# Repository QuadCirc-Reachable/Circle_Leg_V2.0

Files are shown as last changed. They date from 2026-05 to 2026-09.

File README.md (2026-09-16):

# Circle_Leg_V2 — REACHABLE (QuadCirc) Full-Size Wheel-Leg Wheelchair Firmware

<p align="center">
  
  
  
  
  
</p>

<p align="center">
  <b>English</b> | <a href="README_zh.md">中文</a>
</p>

<p align="center">
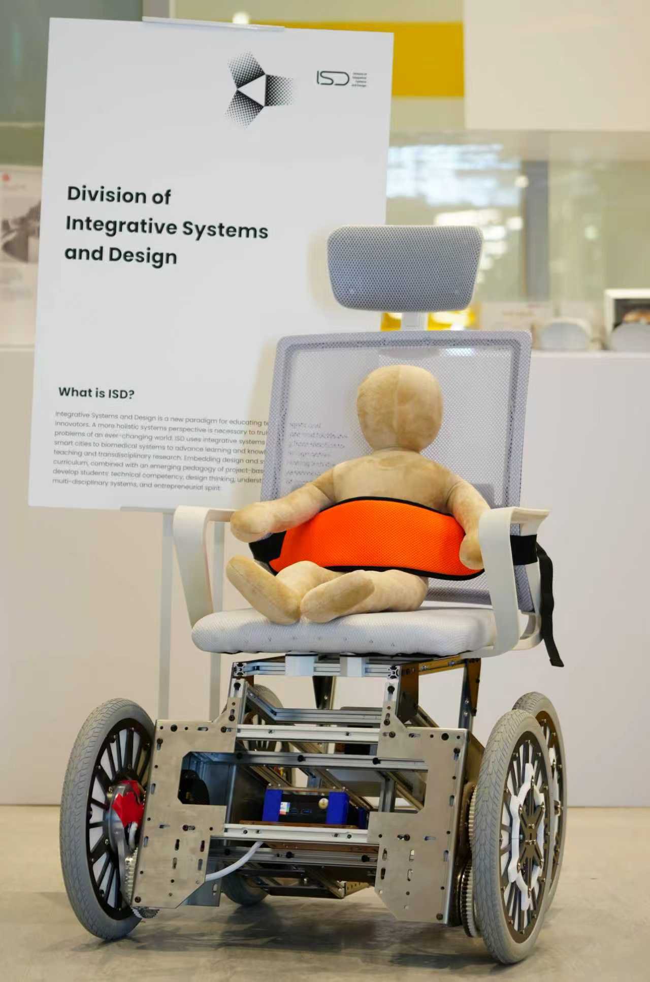
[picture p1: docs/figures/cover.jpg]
Full-size REACHABLE prototype on display at HKUST ISD
  
</p>
<p align="center"><sub>The full-size prototype on display at HKUST ISD</sub></p>

Embedded control firmware for the **full-size REACHABLE (QuadCirc) electric wheelchair**. It has four
**CircLeg** eccentric wheel-leg modules. Each one rolls as an ordinary wheel on flat ground and turns
into a stepping leg to lift the chassis over the 5–18 cm curbs, thresholds and single steps that
wheelchair users meet every day. HKUST Final Year Design Project **SL05a-25** (2025–2026).

---

## Overview

Each CircLeg puts the wheel hub at an eccentric offset *r* inside a wheel of radius *R*. Rotating
the hub raises or lowers that corner of the chassis, and the wheel stays in contact with the ground
the whole time. With only **two motors per corner** (one wheel motor, one leg motor), the firmware:

- **Drives** like a normal wheelchair: skid-steer inverse kinematics for the trapezoidal chassis,
  four D-pad speed tiers, acceleration limits and smoothing.
- **Rides comfortably (COMFORT mode):** variable-impedance active suspension that maps a virtual
  Cartesian spring-damper to per-leg MIT gains, IMU body leveling, an online mass estimate, and
  **warp** (diagonal-twist) compensation that keeps all four wheels grounded.
- **Climbs steps (CLIMBING mode):** a per-leg state machine that detects step contact from the
  motor **torque residual** plus the wheel-speed drop, then follows a purely geometric climbing
  trajectory. The front pair climbs first and the back pair follows.
- **Stays safe:** host link-loss detection (500 ms), smooth mode transitions, singularity clamping,
  and live-tunable debug structs for SEGGER Ozone.

Related repositories:

| Repository | Content |
|---|---|
| **Circle_Leg_V2** (this repo) | Firmware for the full-size prototype (final deliverable), PCB and CAD |
| [Circle_Leg_V1.0](https://github.com/QuadCirc-Reachable/Circle_Leg_V1.0) | Firmware for the half-size proof-of-concept prototype |
| [Circle_Leg_Host_V2.0](https://github.com/QuadCirc-Reachable/Circle_Leg_Host_V2.0) | Host software: gamepad link + optional RealSense curb vision (Python package) |
| [Circle_Leg_Host_V1.0](https://github.com/QuadCirc-Reachable/Circle_Leg_Host_V1.0) | Previous single-script gamepad → UART bridge |

---

## Demo

<p align="center">
  <a href="https://youtu.be/onJCvx1d8Sw">
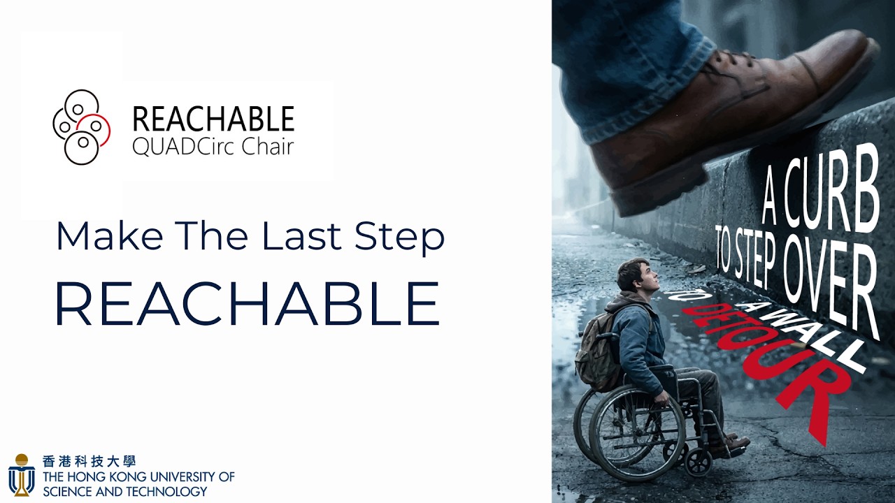
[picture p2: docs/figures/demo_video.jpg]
REACHABLE pitch video on YouTube
    
  </a>
</p>

<p align="center">
  ▶ <a href="https://youtu.be/onJCvx1d8Sw">Watch the REACHABLE pitch video on YouTube</a>
</p>

---

## Key Results

Full-size prototype, as reported in the team's final project report (June 2026):

| Objective | Target | Demonstrated |
|---|---|---|
| Basic locomotion | ≥ 1.2 m/s, differential steering | **1.49 m/s** operating (up to ≈ 2.2 m/s), emergency stop on link loss |
| CircLeg actuation | ±180° within 3 s | **≈ 0.8 s**, critically damped |
| Step climbing | 5–18 cm, seat pitch within ±15° | **5–18 cm**, seat pitch within **±5°** |
| Attitude & suspension | Level within ±10° on slopes | Chassis level within **±2–3°**; warp compensation operational |

> Measured with on-board telemetry (motor encoders, IMU, CAN-reported current) and debugger
> inspection, not with external instruments.

---

## System Architecture

```
┌──────────────────────────┐  UART 2 Mbit/s (CH343)   ┌──────────────────────────────────────────────┐
│ Host (Jetson Orin Nano)  │ ── PC_Msg @ 30 Hz ─────► │ STM32G473 · FreeRTOS                         │
│ Circle_Leg_Host_V2       │ ◄── Reachable_Msg ────── │                                              │
│ Xbox gamepad → frames    │                          │  PC_Comm (link watchdog 500 ms)              │
└──────────────────────────┘                          │     │                                        │
                                                      │     ▼                                        │
┌──────────────────────────┐        SPI               │  Chassis_Task  (500 Hz, 2 ms)                │
│ IMU  ICM-42688-P         │ ───────────────────────► │  ┌────────────────────────────────────────┐  │
└──────────────────────────┘                          │  │ Chassis state machine                  │  │
                                                      │  │ IDLE · ENERGY_SAVING · COMFORT · CLIMB │  │
                                                      │  ├────────────────────────────────────────┤  │
                                                      │  │ Impedance · GroundContact (warp) ·     │  │
                                                      │  │ Climbing FSM · Body PID · Inverse kin. │  │
                                                      │  └───────────────────┬────────────────────┘  │
                                                      │        Wheel_Leg ×4 (FL · FR · BL · BR)       │
                                                      └──────────┬─────────────────────┬─────────────┘
                                                        CAN 1 Mbit/s            CAN 1 Mbit/s
                                                                 ▼                     ▼
                                                  4× HT8115 wheel motors   4× DM J10010L-2EC leg motors
                                                  (MIT velocity mode)      (MIT impedance mode)
```

<p align="center">
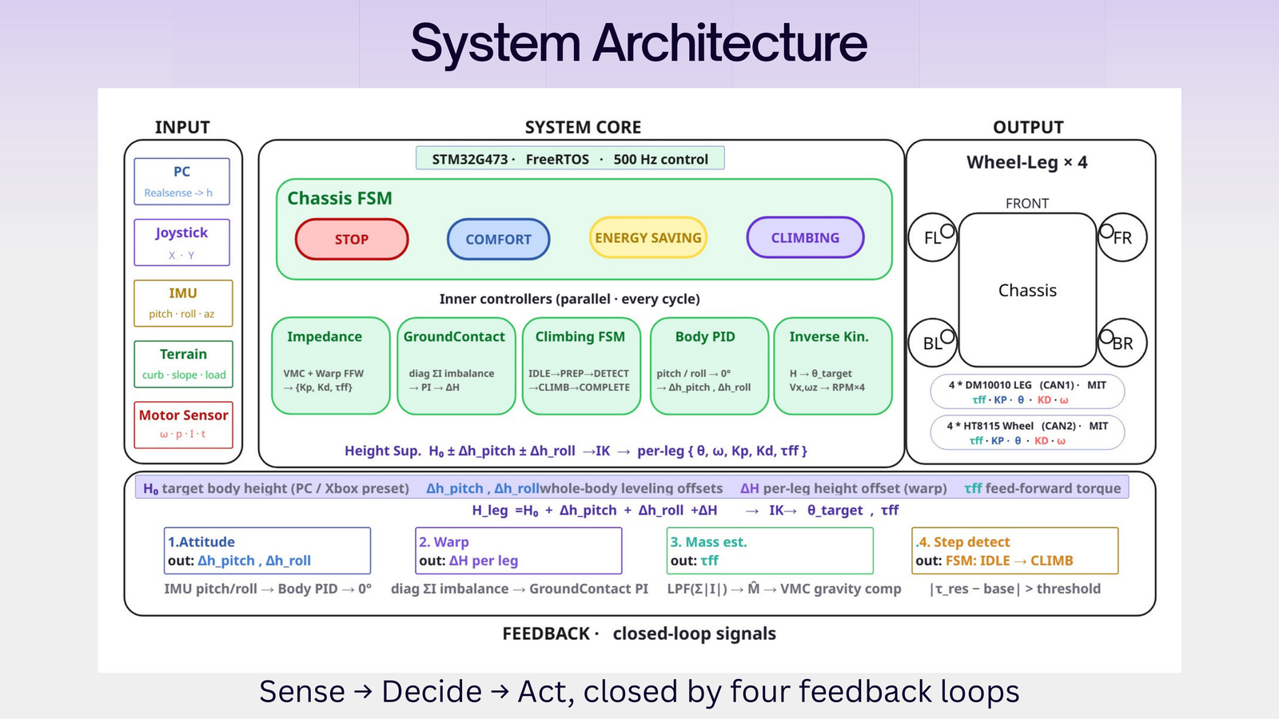
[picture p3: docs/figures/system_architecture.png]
System architecture
  
</p>

Every 2 ms the chassis task reads the latest gamepad command and the IMU attitude. It runs the
active mode's controllers, turns per-leg **height** targets into leg angles and MIT commands
`{θ, ω, Kp, Kd, τ_ff}`, sends one CAN frame per motor, and queues the telemetry for the host.

---

## Control Design

### Eccentric wheel-leg kinematics

<p align="center">
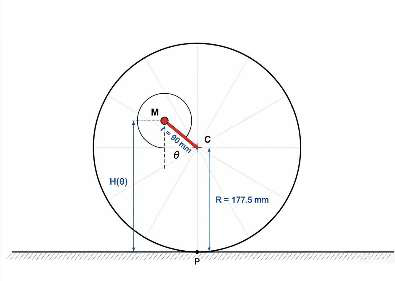
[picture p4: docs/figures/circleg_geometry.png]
CircLeg geometry
  
</p>

With the hub offset *r* = 90 mm inside a wheel of radius *R* = 177.5 mm, the V2 firmware measures
the leg angle from the **lowest** pose (θ = 0°) to the **highest** pose (θ = 180°):

$$H(\theta) = R - r\cos\theta, \qquad \theta = \arccos\frac{R - H}{r}, \qquad \frac{\partial H}{\partial \theta} = r\sin\theta$$

The Jacobian vanishes at 0° and 180°, so every controller clamps the working range away from these
singularities.

### Chassis modes

| Mode | Wheels | Legs | Notes |
|---|---|---|---|
| **IDLE** | Stopped | Low-stiffness hold | Safe state; also entered on host link loss |
| **ENERGY_SAVING** | Joystick | Near 0° (lowest stance), stiff hold | Minimum power; ramps smoothly when leaving COMFORT |
| **COMFORT** | Joystick | Variable-impedance suspension + leveling + warp | Height presets on A/X/LB/RB/Y/B |
| **CLIMBING** | Joystick + auto advance | Per-leg climbing FSM | Front pair first, back pair follows |

`ML` / `MR` step backwards / forwards through IDLE → ENERGY_SAVING → COMFORT → CLIMBING. The
CALIBRATION, FREE_CONTROL and DEBUG states are compiled in but not in the live cycle. The DM leg
motors store their zero at the lowest pose in flash, so no calibration is needed at power-up.

### COMFORT — variable-impedance suspension

A virtual Cartesian spring-damper $(k_v, c_v)$ at each wheel contact point is mapped into joint
space through the eccentric Jacobian:

$$K_{p,i} = \left(\frac{\partial H}{\partial \theta_i}\right)^2 k_{v,i}, \qquad K_{d,i} = \left(\frac{\partial H}{\partial \theta_i}\right)^2 c_v, \qquad \tau_{ff,i} = \left(\frac{\hat M}{4} + m_\text{leg}\right) g \,\frac{\partial H}{\partial \theta_i} + \tau_{\text{warp},i}$$

- **Mass estimate** $\hat M$: low-pass-filtered sum of leg currents. It is frozen while the height
  target is slewing, so the unloading transient doesn't collapse the feed-forward.
- **Body leveling**: roll / pitch PID loops output per-leg height offsets. Gyro-rate damping and a
  load-adaptive gain scale keep the same tuning stable with or without a rider.
- **Warp**: see below. Overloaded diagonals get softer $k_v$ and underloaded ones are pushed down.

### Warp compensation

<p align="center">
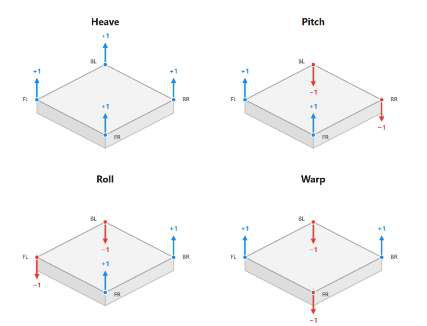
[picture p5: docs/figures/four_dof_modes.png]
Heave, pitch, roll and warp modes
  
</p>

A rigid four-contact chassis has four height modes: heave, pitch, roll and **warp**. Pitch and roll
PID loops can't see warp, so on uneven floors one wheel can hang in the air. The firmware measures
warp directly from the diagonal current imbalance, with no extra sensor:

$$e_\text{warp} = \tfrac12\left(I_{FL} + I_{BR}\right) - \tfrac12\left(I_{FR} + I_{BL}\right)$$

It closes a dedicated loop on it: Kp / feed-forward modulation in COMFORT, and a PI loop on the
per-leg height offset in CLIMBING.

### CLIMBING — step-climbing pipeline

```
HOMING_IN ──► WAIT_START ──(X)──► PREP ──► DETECT ──► CLIMBING ──► COMPLETE ──► HOMING_OUT
 legs → 0°     hold at 0°          lift to    torque-residual  geometric    front pair done →
                                   165°, lean + wheel-drop     trajectory   nose-down lean,
                                   nose-up    score ≥ 1        (kinematic)  back pair repeats
```

- **Detection**: the torque residual $\tau_\text{res} = \tau_\text{fb} - \tau_\text{gravity}$ is tracked
  against an adaptive baseline and combined with a wheel-speed-drop score. Front and back legs have
  separate thresholds, and detection is inhibited while turning.
- **Trajectory**: the leg angle follows the geometry of a wheel rolling over the step edge, with
  step height *h* as a parameter. Auto chassis advance pushes the chassis through while the front
  wheels sit on the step.
- **Weight shift**: nose-up lean while the fronts climb. Afterwards a front-leg drop moves the CoM
  forward to unload the back wheels. Every offset is eased in and out with smoothstep ramps.
- Once both front legs are COMPLETE, pressing **X** again forces the back pair to climb, bypassing
  the detection gates, in case automatic detection doesn't fire.

The full design log, including every tuning decision behind the `dbg_ctrl` parameters, is in
[docs/UNIFIED_CONTROL_REFACTOR.md](docs/UNIFIED_CONTROL_REFACTOR.md).

### Locomotion

The trapezoidal chassis uses per-axle skid-steer gains so it tracks straight lines without drifting:

$$V_{FL/BL} = V_x - \omega_z k_{F/B}, \qquad V_{FR/BR} = V_x + \omega_z k_{F/B}, \qquad k_{F} = \frac{W_F}{W_\text{avg}},\; k_{B} = \frac{W_B}{W_\text{avg}}$$

A wheel-leg decoupling feed-forward cancels the wheel motion that hub rotation would otherwise cause,
so the chair doesn't lurch when the ride height changes.

---

## Repository Structure

```
Circle_Leg_V2/
├── Applications/                   # Application layer (this project)
│   ├── Chassis.hpp/.cpp            # Mode state machine, leveling, IK, climbing orchestration
│   ├── Chassis_Task.hpp/.cpp       # FreeRTOS 500 Hz control task
│   ├── Wheel_Leg.hpp/.cpp          # One CircLeg corner: height↔angle, MIT leg pipeline, wheel loop
│   ├── Impedance_Controller.*      # Variable-impedance suspension, mass estimate, warp modulation
│   ├── Ground_Contact.*            # Warp PI compensator
│   ├── Climbing_Dynamics.*         # Per-leg climbing FSM, step detection, trajectory
│   ├── Controller.*                # Joystick → (Vx, Wz), D-pad speed tiers, slew + LPF
│   ├── PC_Comm.*                   # Host UART link (RosComm framing), link watchdog
│   ├── Robot_Config.*              # Motor objects, CAN IDs, per-leg parameters
│   ├── Robot_Params.hpp            # Geometry, masses, IMU mounting, gains, limits
│   ├── Comm_Msg.hpp                # PC_Msg / Reachable_Msg layouts, button bitmasks
│   ├── Cust_Types.hpp, Helper.hpp  # Shared types and helpers
│   └── DM_Motor_Test.*             # Stand-alone DM J10010L bring-up test (USE_DM_MOTOR_TEST)
├── Core/                           # CubeMX HAL init + UserTask.cpp (task creation)
├── Drivers/, Middlewares/          # STM32G4 HAL, CMSIS, CMSIS-DSP (vendor)
├── RM2025-Core/                    # Submodule → private RM2025-Core (motors, CAN, IMU, RTOS)
├── hardware/
│   ├── power-distribution-board/   # KiCad 9 PCB: dual-battery 24 V power distribution
│   └── interface-cad/              # SolidWorks interface assembly and parts
├── docs/
│   ├── TECHNICAL_REPORT.md         # Control-system technical report (derivations)
│   ├── UNIFIED_CONTROL_REFACTOR.md # Climbing / leg-control design log
│   ├── CODE_STRUCTURE.txt          # Class map and control-flow notes
│   └── figures/
├── Makefile, Core.mk               # GNU Make build (arm-none-eabi-gcc)
├── RM2024-Template-G473.ioc        # STM32CubeMX project
├── stm32g473vetx_flash.ld          # Linker script
└── startup_stm32g473xx.s
```

---

## Getting Started

### Prerequisites

- `arm-none-eabi-gcc` (tested with GCC 12.2 from MSYS2) and GNU Make
- A SWD probe: SEGGER J-Link (Ozone / J-Flash) or ST-Link (STM32CubeProgrammer)
- Read access to the private
  [QuadCirc-Reachable/RM2025-Core](https://github.com/QuadCirc-Reachable/RM2025-Core) repository

> **RM2025-Core** is an internal library of the HKUST ENTERPRIZE RoboMaster team. It is linked as a
> git submodule pointing to a private repository and is **not** part of this repository's contents.

### Clone & build

```bash
git clone --recurse-submodules https://github.com/QuadCirc-Reachable/Circle_Leg_V2.0.git
cd Circle_Leg_V2.0
# already cloned without submodules?  git submodule update --init

make -j8
# → build/RM2024-Template-G473.elf / .hex / .bin
```

Every commit pins the exact RM2025-Core snapshot it was built with, so checking out any old commit
and running `git submodule update` rebuilds it byte-for-byte.

### Flash & debug

Flash `build/RM2024-Template-G473.elf` (or `.hex`) over SWD with Ozone, J-Flash or
STM32CubeProgrammer. For live tuning, open the ELF in SEGGER Ozone and watch or edit these globals:

| Global | Purpose |
|---|---|
| `dbg_ctrl` | Live-tunable climbing parameters (thresholds, pitch bias, ramps, speed ratios) |
| `DbgSummary` / `dbg_climb_plot` | Most useful signals for plotting at 500 Hz |
| `dbg_wheel_test_enable` / `dbg_wheel_test_rpm` | Wheel test bypass (`CHASSIS_DEBUG_SNAPSHOT`) |

### Configuration

| File | What to change |
|---|---|
| `Applications/Robot_Params.hpp` | Geometry, masses, IMU mounting / level trim, speed tiers, leveling gains, limits |
| `Applications/Robot_Config.cpp` | Motor IDs, CAN bus, direction flags |
| `Core/Inc/AppConfig.h` | RM2025-Core module switches (IMU, DM / HT motors, RosComm, `USE_DM_MOTOR_TEST`) |

---

## Operator Controls

Xbox gamepad on the host (see [Circle_Leg_Host_V2.0](https://github.com/QuadCirc-Reachable/Circle_Leg_Host_V2.0)):

| Input | Function |
|---|---|
| Left stick | Forward / backward speed |
| Right stick | Turn rate |
| `ML` / `MR` (View / Menu) | Previous / next chassis mode |
| D-pad ↓ ← → ↑ | Speed tier LOW 20 / MID_LOW 40 (default) / MID_HIGH 80 / HIGH 120 wheel RPM |
| `A` `X`/`LB` `RB` `Y` `B` | COMFORT ride-height presets: leg angle 45° / 90° / 135° / 145° / 165° |
| `X` in CLIMBING | Start the climb (WAIT_START → PREP); once the front pair is COMPLETE, press again to force the back pair |

---

## Communication Protocol

USART2 at **2 Mbit/s**, RosComm framing with CRC16:

```
| SOF 0xAA | len | ID 0xFF | CRC16(header) | payload (14 B) | CRC16(frame) |   → 21 bytes
```

`PC_Msg` (host → MCU, little-endian, packed):

| Field | Type | Range / meaning |
|---|---|---|
| `left_joystick.angle_x10_msg` | int16 | 0–3600 (deg × 10), −1 = released |
| `left_joystick.r_x1000_msg` | uint16 | 0–1000 (deflection) |
| `right_joystick.angle_x10_msg` | int16 | 0–3600, −1 = released |
| `right_joystick.r_x1000_msg` | uint16 | 0–1000 |
| `Left_trigger_x1000_msg` / `Right_trigger_x1000_msg` | uint16 | 0–1000 |
| `button_status` | uint8 | bit 0–7: LB, RB, X, A, B, Y, ML, MR |
| `dpad_status` | uint8 | bit 0–3: Up, Down, Left, Right |

`Reachable_Msg` (MCU → host, 40 bytes) reports each corner's leg position (deg × 10) and wheel RPM.
The field names still say GM6020 / M3508, left over from the half-size hardware.

Host V2.0 can also send RealSense curb-detection results (`0xFC`) and accept a vision-control
heartbeat (`0xFD`). This firmware consumes only the `0xFF` gamepad link. The MCU-side changes
needed to close the vision-in-the-loop climb are in Host V2.0's
[MCU integration guide](https://github.com/QuadCirc-Reachable/Circle_Leg_Host_V2.0/blob/main/docs/MCU_Integration_Guide.md).

---

## Hardware

<div align="center">
<table>
  <tr>
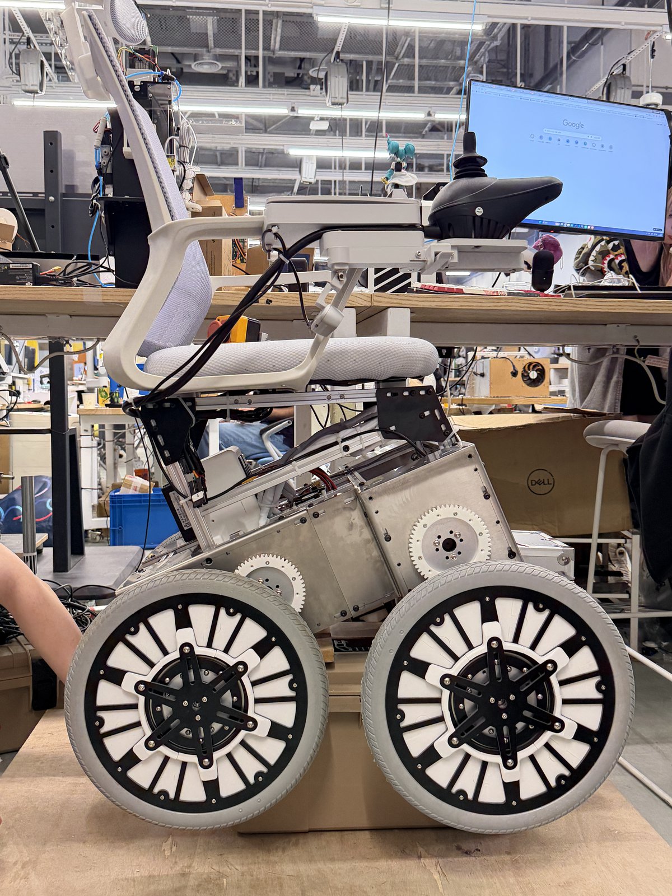
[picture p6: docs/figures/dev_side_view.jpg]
Side view of the full-size prototype during development
    <td align="center"><br><sub>Side view during development</sub></td>
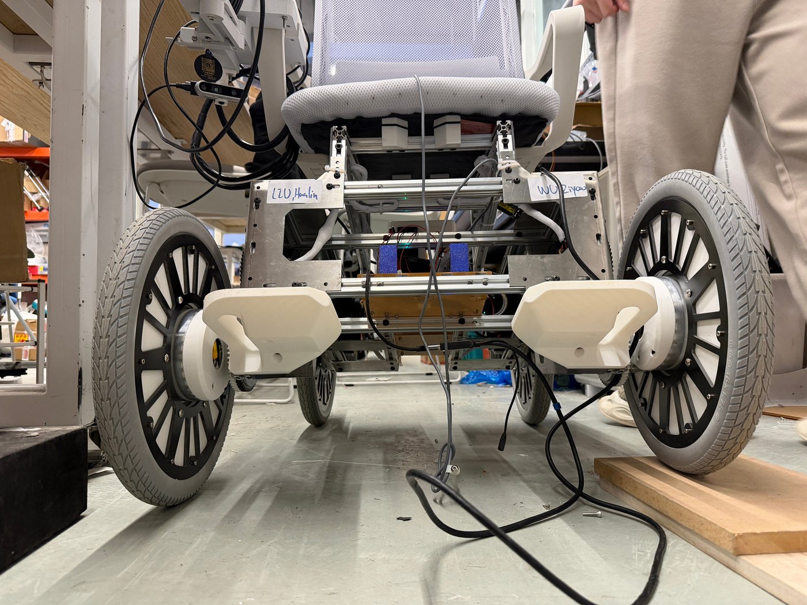
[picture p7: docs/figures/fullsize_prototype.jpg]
CircLeg modules, front view
    <td align="center"><br><sub>CircLeg modules, front view</sub></td>
  </tr>
</table>
</div>

| Item | Specification |
|---|---|
| MCU | STM32G473VET6, Cortex-M4F @ 170 MHz (ENTERPRIZE G4 control board) |
| RTOS | FreeRTOS, 1 kHz tick; chassis task 500 Hz |
| Wheel motors | 4× HT8115, MIT velocity mode |
| Leg motors | 4× DM J10010L-2EC, MIT impedance mode |
| Buses | 2× classic CAN @ 1 Mbit/s (FDCAN peripheral); USART2 @ 2 Mbit/s to host |
| IMU | ICM-42688-P (SPI) |
| Geometry | *R* = 177.5 mm, *r* = 90 mm; track 620 / 480 mm (front / back), wheelbase 385 mm |
| Mass | ≈ 39 kg vehicle |
| Power | 2× DJI TB48 (22.8 V); 24→19 V and 24→5 V converters |
| Host | Jetson Orin Nano + Intel RealSense D435 (curb perception) |

### Power distribution board

`hardware/power-distribution-board/` is a KiCad 9 project. Two battery inputs are OR-ed through
LM74700 ideal-diode controllers with BSC070N10NS5 MOSFETs, with TVS protection and a fuse. The
24 V rail is split to eight motor ports (four leg, four chassis), the mini PC, the control board and
a fan, using XT30 connectors. Custom footprints are in `Library.pretty/`. Jason Chan helped
develop this board.

### Interface CAD

`hardware/interface-cad/` holds the SolidWorks assembly `Assem3.SLDASM` and its parts.

---

## Documentation

| Document | Content |
|---|---|
| [docs/TECHNICAL_REPORT.md](docs/TECHNICAL_REPORT.md) | Control-system report: kinematics, leveling, impedance, warp, climbing, RTOS |
| [docs/UNIFIED_CONTROL_REFACTOR.md](docs/UNIFIED_CONTROL_REFACTOR.md) | Climbing pipeline and leg-control design log, with tuning history |
| [docs/CODE_STRUCTURE.txt](docs/CODE_STRUCTURE.txt) | Class hierarchy, per-mode control flow, key formulas |

---

## Team

<p align="center">
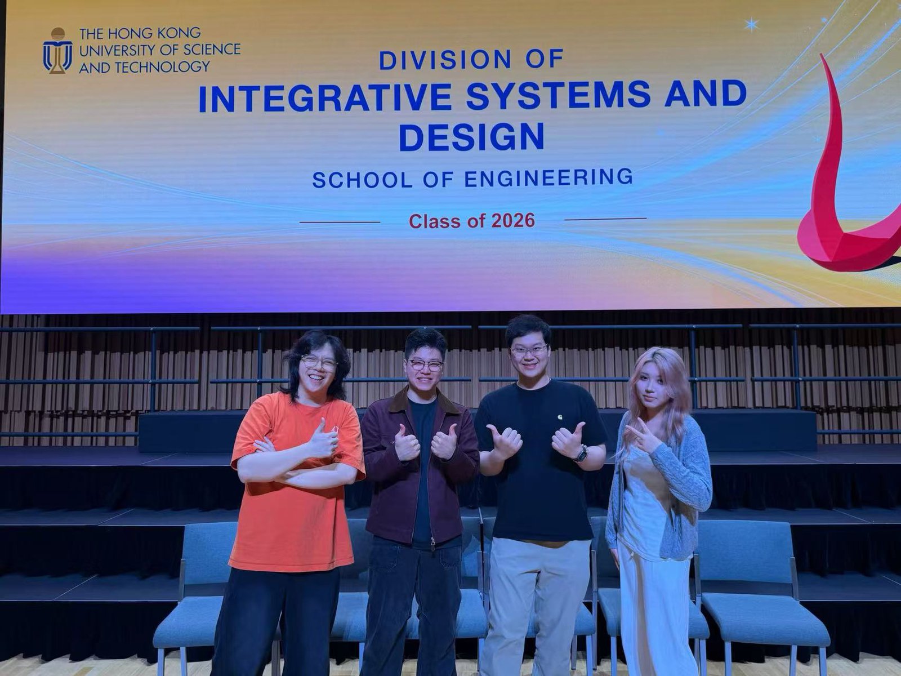
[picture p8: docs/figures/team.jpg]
The REACHABLE team at the HKUST ISD Class of 2026 event
  
</p>

**REACHABLE (QuadCirc)**, HKUST Final Year Design Project SL05a-25:

- **LIU Hualin** — embedded control lead: motor and MCU selection, dual-CAN hardware, and all of the firmware and control algorithms in this repository
- **FANG Ruoyun** — perception (RealSense curb detection) and HMI
- **WU Ziyao** — mechanical architecture, host–MCU communication
- **XU Jusen** — mechanical lead (CircLeg bracket, chassis, DFM/DFA)

Supervisors: Prof. Chi-Ying TSUI and Prof. Winnie Suk Wai LEUNG; co-supervisor Prof. SHI Ling.

---

## License

The application code in this repository is released under the [MIT License](LICENSE).
Third-party components keep their own licenses: STM32 HAL / CMSIS in `Drivers/` and `Middlewares/`,
and template files (`Core.mk`, `Core/Src/UserTask.cpp`) from the ENTERPRIZE RoboMaster team.
The `RM2025-Core` submodule is private and not covered by this license.

## Acknowledgments

- HKUST ENTERPRIZE RoboMaster team for RM2025-Core and the G4 project template
- Jason GAN (RM2024) for the original HT8115 motor driver
- Jason Chan for helping develop the power distribution board
- STMicroelectronics (HAL, CMSIS) and the FreeRTOS project
- Our friends and classmates at HKUST ISD

<p align="center">
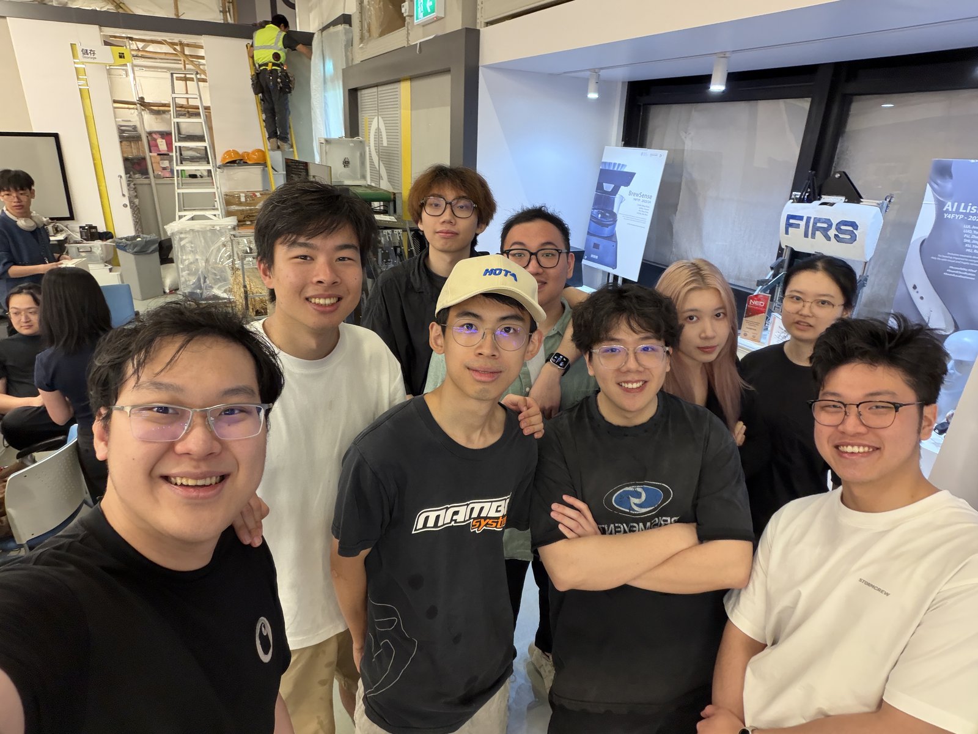
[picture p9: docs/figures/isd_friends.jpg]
With friends from HKUST ISD
  
</p>
<p align="center"><sub>With our friends from HKUST ISD</sub></p>

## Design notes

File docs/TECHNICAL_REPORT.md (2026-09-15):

# Circle Leg V1 — Final Year Project Technical Report

> **Scope note (Circle_Leg_V2):** this report was written for the half-size prototype (Circle_Leg_V1: M3508 wheels, HT8115 legs) and uses V1's angle convention $H(	heta) = R + r\cos	heta$. The control architecture carries over to V2 unchanged; see the [README](../README.md) for the full-size hardware, parameters and V2's convention $H(	heta) = R - r\cos	heta$ (legs zeroed at the lowest pose).

## Table of Contents

1. [Project Overview](#1-project-overview)
2. [System Architecture](#2-system-architecture)
3. [Hardware Configuration](#3-hardware-configuration)
4. [Eccentric Wheel-Leg Kinematics](#4-eccentric-wheel-leg-kinematics)
5. [Chassis State Machine](#5-chassis-state-machine)
6. [Body Leveling — Pitch/Roll PID](#6-body-leveling--pitchroll-pid)
7. [Inverse Kinematics — Skid-Steer Model](#7-inverse-kinematics--skid-steer-model)
8. [Wheel–Leg Decoupling Compensation](#8-wheel-leg-decoupling-compensation)
9. [Virtual Model Control (VMC)](#9-virtual-model-control-vmc)
10. [Impedance Controller — Active Suspension](#10-impedance-controller--active-suspension)
11. [Ground Contact — Warp Compensation](#11-ground-contact--warp-compensation)
12. [Climbing Dynamics — Step Climbing](#12-climbing-dynamics--step-climbing)
13. [Motor Control Pipeline](#13-motor-control-pipeline)
14. [Communication Protocol](#14-communication-protocol)
15. [RTOS Task Structure](#15-rtos-task-structure)
16. [Summary of Key Formulas](#16-summary-of-key-formulas)
17. [File Reference](#17-file-reference)

---

## 1. Project Overview

This project implements a **4-wheeled eccentric-leg robot** (Circle Leg) on an **STM32G473** microcontroller, running **FreeRTOS** at a **500 Hz** control loop. The robot features:

- **Four independent wheel-leg units**, each consisting of a **wheel motor** (DJI M3508) and a **leg motor** (HT8115, MIT control mode).
- **Variable-impedance active suspension** (Comfort Mode) for terrain adaptation.
- **Kinematic step-climbing** (Climbing Mode) using torque-residual step detection and geometric trajectory planning.
- **Ground contact warp compensation** to maintain 4-wheel ground contact on uneven surfaces.
- **PC remote control** via UART with joystick and button inputs.

---

## 2. System Architecture

```
┌──────────────────────────────────────────────────────┐
│                    PC Controller                     │
│           (Joystick + Buttons via UART)              │
└──────────────┬───────────────────────────────────────┘
               │  PC_Msg (13 bytes)
               ▼
┌──────────────────────────────────────────────────────┐
│              Chassis_Task (500 Hz)                   │
│  ┌────────────────────────────────────────────────┐  │
│  │              Chassis (State Machine)            │  │
│  │  ┌──────────┐ ┌──────────┐ ┌──────────────┐   │  │
│  │  │ Pitch/   │ │Impedance │ │  Climbing    │   │  │
│  │  │ Roll PID │ │Controller│ │  Dynamics    │   │  │
│  │  └──────────┘ └──────────┘ └──────────────┘   │  │
│  │  ┌──────────┐ ┌──────────┐                    │  │
│  │  │  Ground  │ │  Inverse │                    │  │
│  │  │  Contact │ │Kinematics│                    │  │
│  │  └──────────┘ └──────────┘                    │  │
│  └────────────────────────────────────────────────┘  │
│          │            │           │          │        │
│      ┌───┴───┐   ┌───┴───┐  ┌───┴───┐  ┌───┴───┐   │
│      │FL Leg │   │FR Leg │  │BL Leg │  │BR Leg │   │
│      │M3508+ │   │M3508+ │  │M3508+ │  │M3508+ │   │
│      │HT8115 │   │HT8115 │  │HT8115 │  │HT8115 │   │
│      └───────┘   └───────┘  └───────┘  └───────┘   │
└──────────────────────────────────────────────────────┘
```

---

## 3. Hardware Configuration

### 3.1 Mechanical Parameters

| Parameter | Symbol | Value | Unit |
|---|---|---|---|
| Wheel Radius | $R$ | 160 | mm |
| Eccentric Offset (Leg Length) | $r$ | 65 | mm |
| Wheelbase | $L$ | 270 | mm |
| Front Track Width | $W_F$ | 531 | mm |
| Back Track Width | $W_B$ | 395 | mm |
| Robot Mass | $M$ | 10.0 | kg |
| Leg Mass | $m_{leg}$ | 0.5 | kg |

### 3.2 Motor Configuration

| Motor | Type | Quantity | Bus | Role |
|---|---|---|-----|---|
| M3508 | Brushless DC (DJI) | 4 | CAN 2 | Wheel drive, PID velocity control |
| HT8115 | Torque motor | 4 | CAN 3 | Leg actuation, MIT impedance control |

### 3.3 IMU

- On-board IMU providing Euler angles (Yaw, Pitch, Roll), calibrated gyro, and earth-frame linear acceleration (gravity removed).
- IMU mounting roll offset: **182.91°** (compensated in software).
- Low-pass filter on angles: $\alpha = 0.02$ (~4 Hz cutoff at 500 Hz).

---

## 4. Eccentric Wheel-Leg Kinematics

Each wheel-leg unit uses an **eccentric linkage**: a motor rotates the leg by angle $\theta$, changing the chassis height.

### 4.1 Height–Angle Relationship

$$H(\theta) = R + r \cdot \cos(\theta)$$

Where:
- $H$ = ground-to-motor-center height (m)
- $R$ = wheel radius (m)
- $r$ = eccentric offset / leg length (m)
- $\theta$ = leg angle (0° = fully extended/highest, 180° = fully retracted/lowest)

### 4.2 Inverse: Height to Angle

Given a target height $H_{target}$:

$$\cos(\theta) = \frac{H_{target} - R}{r}$$

$$\theta = \arccos\left(\frac{H_{target} - R}{r}\right)$$

**Safety:** clamped to $[10°, 170°]$ to avoid singularities at 0° and 180°.

### 4.3 Velocity Feedforward (Height Rate to Angular Velocity)

From $\dot{H} = -r \sin(\theta) \cdot \dot{\theta}$:

$$\dot{\theta} = \frac{-\dot{H}}{r \cdot (\sin(\theta) + \epsilon)}$$

Where $\epsilon = 0.1$ is a damping term to avoid division-by-zero near singularities.

### 4.4 Bending Direction

Each leg has a `bending_direction` parameter ($+1$ or $-1$) that selects between the positive and negative angle solution, allowing the robot to switch between "outward" and "inward" leg configurations.

---

## 5. Chassis State Machine

The system operates through the following states, controlled by gamepad buttons:

| State | ID | Description |
|---|----|---|
| **CALIBRATION** | 0 | Re-enters HT motor mode, sets zero position, then transitions to IDLE |
| **IDLE** | 1 | All motors stopped, zero output |
| **ENERGY_SAVING** | 2 | Legs at 0° (folded), stiff position hold ($K_p=20$, $K_d=1.5$), basic wheel driving |
| **COMFORT** | 3 | **Variable-impedance active suspension** with IMU-based body leveling and warp compensation |
| **CLIMBING** | 4 | **Per-leg kinematic step climbing** with torque-residual detection, front-first then rear-legs |
| **FREE_CONTROL** | 5 | Direct trigger-to-angle mapping for manual leg positioning |
| **DEBUG** | 6 | Height control via buttons, no PID leveling (for testing) |

### Mode Transition

- **ML + MR** simultaneously → CALIBRATION
- **ML** (rising edge) → Previous state
- **MR** (rising edge) → Next state

### Smooth Kp Ramp on COMFORT Exit

When leaving COMFORT mode, the impedance Kp/Kd values are captured and linearly ramped to the target mode's values over **200 frames (0.4 s)** to prevent sudden torque changes:

$$K_p(t) = K_{p,\text{exit}} + \alpha(t) \cdot (K_{p,\text{target}} - K_{p,\text{exit}})$$

where $\alpha(t) = t / T_{ramp}$ increases from 0 to 1.

---

## 6. Body Leveling — Pitch/Roll PID

Two independent PID controllers maintain chassis level using IMU feedback:

| PID | $K_p$ | $K_i$ | $K_d$ | Integral Limit | Output Limit |
|-----|---|---|---|---|---|
| Roll | 0.015 | 0.0002 | 0.00012 | 1000 | 0.08 m |
| Pitch | 0.015 | 0.00015 | 0.00012 | 1000 | 0.08 m |

**PID output** is a height offset in meters. Distribution to four legs:

| Leg | Pitch Sign | Roll Sign |
|-----|---|---|
| FL (Front-Left)  | $+1$ | $-1$ |
| FR (Front-Right) | $+1$ | $+1$ |
| BL (Back-Left) | $-1$ | $-1$ |
| BR (Back-Right)  | $-1$ | $+1$ |

Per-leg target height:

$$H_i = H_{target} + s_{pitch,i} \cdot \Delta H_{pitch} + s_{roll,i} \cdot \Delta H_{roll} + \Delta H_{mode,i}$$

Where:
- $\Delta H_{pitch} = \text{PID}_{pitch}(0, \theta_{pitch})$
- $\Delta H_{roll} = \text{PID}_{roll}(0, \theta_{roll})$
- $\Delta H_{mode,i}$ = mode-specific compensation (warp, climbing, etc.)

---

## 7. Inverse Kinematics — Skid-Steer Model

The robot uses **asymmetric skid-steer** kinematics ($W_F \neq W_B$):

$$V_{FL} = V_x - \omega_z \cdot k_F, \qquad V_{FR} = V_x + \omega_z \cdot k_F$$

$$V_{BL} = V_x - \omega_z \cdot k_B, \qquad V_{BR} = V_x + \omega_z \cdot k_B$$

Where the differential gain per axle:

$$k_F = \frac{W_F}{W_{avg}}, \qquad k_B = \frac{W_B}{W_{avg}}, \qquad W_{avg} = \frac{W_F + W_B}{2}$$

**Normalization:** If any wheel RPM exceeds `MAX_WHEEL_RPM` (80 RPM), all four are proportionally scaled down.

### Joystick Mapping

- **Left stick** → Forward/backward velocity $V_x$ (max ±40 RPM)
- **Right stick** → Rotational velocity $\omega_z$ (max ±40 RPM)
- Deadzone: 200/1000 on radius magnitude

---

## 8. Wheel–Leg Decoupling Compensation

When the leg motor rotates, it mechanically couples into the wheel, causing unintended wheel spin. This is compensated by:

$$n_{wheel,comp} = n_{leg} \cdot \left(1 + \frac{r}{R} \cdot \cos(\theta_{leg})\right) \cdot k_{coupling}$$

Where:
- $n_{leg}$ = leg motor RPM
- $r / R$ = eccentric offset / wheel radius ratio
- $\theta_{leg}$ = current leg angle
- $k_{coupling}$ = coupling sign ($\pm 1$ depending on mounting geometry)

This compensation RPM is added to the wheel motor target before PID execution.

---

## 9. Virtual Model Control (VMC)

Converts a desired vertical force $F_z$ to motor torque via the mechanism Jacobian:

$$\tau = F_z \cdot r \cdot \cos(\theta)$$

Where $\tau$ is motor torque (Nm), $r$ is eccentric offset (m), and $\theta$ is leg angle (rad).

### Gravity Compensation

Each leg compensates for gravitational torque:

$$\tau_{gravity} = -(m_{leg} \cdot g \cdot r \cdot \cos(\theta))$$

This is continuously applied as **feed-forward torque** in the MIT control command.

---

## 10. Impedance Controller — Active Suspension

The core of COMFORT mode. Maps desired **Cartesian impedance** (spring-damper at the wheel contact point) to **joint-space MIT motor parameters**.

### 10.1 Theoretical Derivation

**Eccentric Linkage Jacobian:**

$$J(\theta) = \frac{dH}{d\theta} = -r \cdot \sin(\theta)$$

**Desired Cartesian impedance:**

$$F = k_v \cdot (H_{des} - H) + c_v \cdot (\dot{H}_{des} - \dot{H}) + F_{gravity}$$

**Mapping to MIT control law** ($\tau = K_p \cdot \delta\theta + K_d \cdot \delta\dot{\theta} + \tau_{ff}$):

$$\boxed{K_{p,MIT} = r^2 \cdot \sin^2(\theta) \cdot k_v}$$

$$\boxed{K_{d,MIT} = r^2 \cdot \sin^2(\theta) \cdot c_v}$$

$$\boxed{\tau_{ff} = -F_{load} \cdot r \cdot \sin(\theta)}$$

**Numerical Example** ($\theta=90°$, $r=0.065$ m):
- $r^2 \sin^2(90°) = 0.004225$
- $k_v = 800$ N/m → $K_p = 3.38$ Nm/rad
- $c_v = 250$ Ns/m → $K_d = 1.06$ Nms/rad

### 10.2 Warp Kp Modulation (Ground Contact)

Diagonal load imbalance detection:

$$e_{warp} = \frac{I_{FL} + I_{BR}}{2} - \frac{I_{FR} + I_{BL}}{2}$$

Warp sign pattern: $\{FL: +1, FR: -1, BL: -1, BR: +1\}$

$$k_{v,i} = k_{v,base} \cdot \left(1 - \gamma \cdot s_{warp,i} \cdot \text{clamp}(e_{warp})\right)$$

**Effect:** Overloaded diagonal becomes softer → compresses → redistributes load to the underloaded diagonal.

### 10.3 Dynamic Load Estimation (FFW)

Total mass estimated from motor currents (slow LPF):

$$M_{est} = \frac{\text{LPF}(\sum |I_i|) \cdot K_A \cdot GR}{g}$$

Per-leg gravity compensation:

$$\tau_{ff,i} = -\left(\frac{M_{est}}{4} + m_{leg}\right) \cdot g \cdot r \cdot \sin(\theta_i) + \tau_{warp,i}$$

### 10.4 Mode Entry Ramp

On entering COMFORT, the Kp/Kd values ramp from entry defaults ($K_p=35$, $K_d=1.5$) to the computed impedance values over ~0.4 s:

$$K_p(t) = K_{p,entry} + \alpha(t) \cdot (K_{p,impedance} - K_{p,entry})$$

Where $\alpha$ increments by 0.005 per cycle until reaching 1.0.

---

## 11. Ground Contact — Warp Compensation

### 11.1 Problem

A rigid chassis on 4 contact points has **one over-constrained DOF** (the "warp" or diagonal twist). Pitch and Roll PIDs control 2 of 3 tilting DOFs, leaving warp uncontrolled — one wheel can lift off.

### 11.2 Warp Decomposition

The 4 per-leg height offsets decompose into 4 orthogonal modes:

| Mode | Pattern (FL, FR, BL, BR) | Controller |
|---|---|---|
| Heave | $(+1, +1, +1, +1)$ | `target_chassis_height_` |
| Pitch | $(+1, +1, -1, -1)$ | Pitch PID |
| Roll  | $(-1, +1, -1, +1)$ | Roll PID |
| **Warp** | $(+1, -1, -1, +1)$ | **GroundContact PI** |

### 11.3 PI Controller

$$\Delta H_{warp} = K_p \cdot e_{warp} + K_i \cdot \int e_{warp} \, dt$$

| Parameter | Value |
|---|---|
| $K_p$ | 0.002 m/A |
| $K_i$ | 0.0005 m/(A·s) |
| Max $\Delta H$ | ±20 mm |
| Deadband | 0.15 A |

Output per leg:

$$\Delta H_{FL} = -\Delta H_{warp}, \quad \Delta H_{FR} = +\Delta H_{warp}$$
$$\Delta H_{BL} = +\Delta H_{warp}, \quad \Delta H_{BR} = -\Delta H_{warp}$$

**Anti-windup:** Integral clamped and decayed (×0.990 when in deadband, ×0.999 otherwise).

---

## 12. Climbing Dynamics — Step Climbing

### 12.1 Per-Leg State Machine

```
IDLE → PREP → DETECT → CLIMBING → COMPLETE → (back to IDLE)
```

| Phase | Description |
|---|---|
| **IDLE** | Normal height pipeline |
| **PREP** | Move leg to preparatory angle ($180° - \theta_{prep}$, default 165°) to avoid singularity |
| **DETECT** | Hold at prep angle; monitor **leg torque residual** for step contact |
| **CLIMBING** | Execute **kinematic trajectory** — compensate leg angle as wheel rolls over step |
| **COMPLETE** | Hold at end-of-climb angle; await reset |

**Sequencing:** Front legs (FL, FR) climb first. Rear legs (BL, BR) start automatically when both front legs reach COMPLETE.

### 12.2 Step Detection — Torque Residual Method

The torque residual isolates step-contact forces:

$$\tau_{residual} = \tau_{feedback} - \tau_{gravity\_comp}$$

A slow LPF baseline tracks the DC component:

$$\tau_{baseline}(k) = \alpha \cdot \tau_{residual}(k) + (1-\alpha) \cdot \tau_{baseline}(k-1)$$

Step detection triggers when:

$$|\tau_{residual} - \tau_{baseline}| > \tau_{threshold}$$

held for $t_{confirm} = 20$ ms. Default threshold: **3.0 Nm**.

**Warmup:** First 0.1 s uses fast LPF ($\alpha=0.3$) to converge baseline, then switches to slow ($\alpha=0.02$).

### 12.3 Climbing Kinematic Model

A wheel (radius $R$) connected via an eccentric leg (length $L$) climbs a step of height $h$. The wheel rotates around the step edge point $E$.

**Constraint equation:**

$$\cos(\theta) = \frac{R + L - h - R \cdot \sin(\beta)}{L}$$

Where:
- $\theta$ = leg angle in kinematic model (small $\theta$ = extended)
- $\beta$ = wheel rotation angle around step edge ($\beta_0$ → $90°$)

**Angular velocity coupling:**

$$\dot{\theta} = \frac{R \cdot \cos(\beta) \cdot \dot{\beta}}{L \cdot \sin(\theta)}$$

**Boundary conditions:**
- Start: $\theta = \theta_{prep}$, $\beta = \beta_0 = \arcsin\left(\frac{R - h}{R}\right)$  (from constraint at prep angle)
- End: $\beta = 90°$, $\theta_{end} = \arccos\left(\frac{L - h}{L}\right)$

### 12.4 Trajectory Generation

The climbing angle $\beta$ is integrated at a **constant virtual angular velocity** $\omega_{climb}$ (default 1.0 rad/s), independent of actual wheel speed (which stalls against the step):

$$\beta(k+1) = \beta(k) + \omega_{climb} \cdot \Delta t$$

At each step:
1. Compute $\theta$ from constraint: $\cos(\theta) = \frac{R + L - h - R \sin(\beta)}{L}$
2. Motor angle: $\theta_{motor} = 180° - \theta$ (convention: 180° = highest)
3. Apply climb_sign: FL/FR use $-\theta_{motor}$, BL/BR use $+\theta_{motor}$

### 12.5 Climbing Wheel Forward Drive

During CLIMBING and COMPLETE phases, a forward RPM boost is added:

$$n_{climb} = \omega_{climb} \cdot \frac{60}{2\pi} \cdot k_{scale}$$

where $k_{scale}$ (default 5.0) is the wheel RPM multiplier. The boost is active only when the user pushes forward ($V_x > 0.5$).

### 12.6 Pitch Bias During Climbing

A pitch lean angle biases weight toward the climbing wheels:
- **Front legs climbing** → lean forward ($-3°$ pitch setpoint)
- **Rear legs climbing** → lean backward ($+3°$ pitch setpoint)

---

## 13. Motor Control Pipeline

### 13.1 Wheel Motor Pipeline (M3508)

```
Target RPM → + Decoupling Compensation → Deadzone Check → PID → Motor Output
```

**Wheel Velocity PID** parameters (per motor):
- $K_p = 200$, $K_i = 180$, $K_d = 1.0$
- Integral limit: 15000, Output limit: 16000

**Deadzone:** When target and feedback are both below 15 RPM, output is zeroed and PID is reset to prevent integral windup.

### 13.2 Leg Motor Pipeline (HT8115 — MIT Mode)

```
Target Height → Height-to-Angle → Slew Rate Limiter → MIT Command
```

**MIT Control Law (HT8115):**

$$\tau = K_p \cdot (\theta_{target} - \theta_{fb}) + K_d \cdot (\dot{\theta}_{target} - \dot{\theta}_{fb}) + I_{ff} \cdot K_A$$

Where:
- $K_p$ = position stiffness (Nm/rad, range 0–500)
- $K_d$ = velocity damping (Nms/rad, range 0–5)
- $I_{ff}$ = feed-forward current (A)
- $K_A$ = motor torque constant

**Default MIT parameters:** $K_p = 35$, $K_d = 1.5$ (stiff position hold).

### 13.3 Slew Rate Limiter

Prevents violent leg movements by clamping angle change per cycle:

$$|\Delta\theta_{cmd}| \leq \dot{\theta}_{max} \cdot \Delta t = 400°/\text{s} \times 2\text{ms} = 0.8°/\text{cycle}$$

Includes **angle unwrapping** to handle ±180° wrapping correctly.

---

## 14. Communication Protocol

### 14.1 PC → MCU (PC_Msg, 13 bytes)

| Field | Type | Description |
|---|---|---|
| `left_joystick` | `{angle_x10, r_x1000}` | Left stick: forward/backward |
| `right_joystick` | `{angle_x10, r_x1000}` | Right stick: rotation |
| `Left_trigger_x1000` | `uint16` | Left trigger (0–1000) |
| `Right_trigger_x1000` | `uint16` | Right trigger (0–1000) |
| `button_status` | `uint8` | 8 buttons: LB, RB, X, A, B, Y, ML, MR |

### 14.2 MCU → PC (Reachable_Msg, 40 bytes)

- Motor positions (×10), target positions (×10), temperatures
- Motor RPMs, target RPMs, temperatures

### 14.3 Connection Detection

- Timeout-based: if no message received within threshold, robot enters IDLE.
- On reconnect, button state is forced to 0xFF to prevent false rising edges.

---

## 15. RTOS Task Structure

| Task | Stack | Priority | Rate | Function |
|---|---|---|---|---|
| `Chassis_Task` | 2048 words | 0 | 500 Hz (2 ms delay) | Main control loop |
| `PC_CommTask` | — | — | 100 ms TX | UART communication |

### Startup Sequence

1. Wait 3000 ms for HT8115 motor boot
2. Call `chassis.Init()` — enables all motors, sends ENTER_MOTOR ×20 to HT motors
3. Enter main loop: read PC command → update chassis → transmit CAN → send feedback

---

## 16. Summary of Key Formulas

### Kinematics

| Formula | Equation | Used In |
|---|---|---|
| Height from angle | $H = R + r\cos\theta$ | `Set_Leg_Height`, `CalculateHeightFromAngle` |
| Angle from height | $\theta = \arccos\left(\frac{H-R}{r}\right)$ | `Set_Leg_Height` |
| Velocity feedforward | $\dot\theta = \frac{-\dot H}{r(\sin\theta + \epsilon)}$ | `Set_Leg_Height` |
| Wheel compensation | $n_w = n_l \left(1 + \frac{r}{R}\cos\theta\right)$ | `Wheel_Compensation` |
| VMC (Jacobian) | $\tau = F_z \cdot r \cdot \cos\theta$ | `VMC_Calculation` |
| Gravity torque | $\tau_g = -m \cdot g \cdot r \cdot \cos\theta$ | `Get_LegGravityTorque` |

### Impedance Control

| Formula | Equation |
|---|---|
| MIT Kp mapping | $K_{p} = r^2 \sin^2\theta \cdot k_v$ |
| MIT Kd mapping | $K_{d} = r^2 \sin^2\theta \cdot c_v$ |
| FFW torque | $\tau_{ff} = -F_{load} \cdot r \cdot \sin\theta$ |
| Warp stiffness modulation | $k_{v,i} = k_{v,base}(1 - \gamma \cdot s_i \cdot \hat{e}_{warp})$ |
| Mass estimation | $M = \text{LPF}(\sum|I_i|) \cdot K_A \cdot GR / g$ |

### Climbing

| Formula | Equation |
|---|---|
| Constraint | $\cos\theta = \frac{R + L - h - R\sin\beta}{L}$ |
| Angle rate | $\dot\theta = \frac{R\cos\beta \cdot \dot\beta}{L\sin\theta}$ |
| End angle | $\theta_{end} = \arccos\left(\frac{L-h}{L}\right)$ |
| Start angle | $\beta_0 = \arcsin\left(\frac{R + L(1 - \cos\theta_{prep}) - h}{R}\right)$ |

### Inverse Kinematics (Skid-Steer)

| Wheel | Formula |
|---|---|
| FL | $V_x - \omega_z \cdot k_F$ |
| FR | $V_x + \omega_z \cdot k_F$ |
| BL | $V_x - \omega_z \cdot k_B$ |
| BR | $V_x + \omega_z \cdot k_B$ |

Where $k_F = W_F / W_{avg}$, $k_B = W_B / W_{avg}$.

---

## 17. File Reference

| File | Description |
|---|---|
| `Chassis.hpp / .cpp` | Main chassis state machine, mode handlers, body leveling, inverse kinematics |
| `Wheel_Leg.hpp / .cpp` | Per-leg motor control: height→angle conversion, MIT command, wheel PID, decoupling |
| `Impedance_Controller.hpp / .cpp` | Variable-impedance active suspension: Cartesian→MIT mapping, warp modulation |
| `Climbing_Dynamics.hpp / .cpp` | Per-leg climbing state machine, kinematic trajectory, torque-residual step detection |
| `Ground_Contact.hpp / .cpp` | Warp-mode PI compensator for 4-wheel ground contact |
| `Controller.hpp / .cpp` | Joystick-to-velocity mapping |
| `Robot_Params.hpp` | All mechanical/control constants |
| `Robot_Config.cpp` | Motor/PID/Wheel_Leg instantiation and wiring |
| `Chassis_Task.cpp` | FreeRTOS task: main 500 Hz control loop |
| `PC_Comm.hpp / .cpp` | UART communication with PC controller |
| `Comm_Msg.hpp` | Protocol message structures (PC_Msg, Reachable_Msg) |
| `Cust_Types.hpp` | Enum/struct definitions (Chassis_State, MIT_Params, Wheel_Leg_Params) |
| `Helper.hpp` | Utility functions (angle normalization, deg/rad conversion) |

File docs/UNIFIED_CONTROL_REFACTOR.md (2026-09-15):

# Unified Leg-Control Refactor — Plan & Memory

> Wheelchair project (passenger on board). **Safety-critical:** the leg motors
> allow unlimited 360° rotation, so the controller must NEVER let a leg unwind
> multiple turns (passenger bobs up/down = unsafe). This whole refactor exists
> to make multi-turn unwind *structurally impossible*, not just unlikely.

---

## 0. CLIMBING pipeline (consolidated, current state)

The climb sequence is a per-leg state machine (`Climbing_Dynamics`) wrapped by
a chassis-level stage machine (`Chassis::handleClimbingMode`). Front legs
(FL=0, FR=1) climb first; back legs (BL=2, BR=3) follow. Each leg's
`LegClimbPhase`: IDLE→PREP→DETECT→CLIMBING→COMPLETE.

### Step 1 — enter at theta=0 (transition pose) [HOMING_IN / WAIT_START]
- On `Set_Mode(CLIMBING)`, `climb_stage_ = HOMING_IN`. All legs smoothstep to
  motor-frame 0° (ES-style: matched omega_ff + gravity FFW + Kp/Kd ramp +
  FF wheel comp, A4dd/A4ee). Wheels follow joystick.
- At 0° → `WAIT_START`: hold at 0°, wait for BTN_X. Approaching the PREP
  angle from 0° guarantees a single-direction sweep that never crosses the
  ±180° seam.
- BTN_X → `startClimbAll()` → all 4 legs enter PREP, `climb_stage_=ACTIVE`.

### Step 2 — PREP (synchronized lift + nose-up lean) [phase PREP]
- All 4 legs smoothstep `target_theta` 0 → (180-prep_theta_deg)=165° over
  `prep_ramp_s`=3 s, IN LOCKSTEP (shared ramp clock → no chassis wobble).
  Driven by flat PD (Set_Leg_PD_Torque, Kp=40/Kd=2, A4kk) + gravity FFW
  (adaptive mass, A4oo) + matched omega_ff.
- **Pitch lean-back +10° (nose UP):** `climb_pitch_front_deg=10` shifts CoM
  backward to unload the front wheels for easier step pivot. Applied via
  body PID → per-leg dtheta, LPF-smoothed (A4tt). **GEOMETRIC CAVEAT:**
  at 165° the leg has almost no pitch authority (dH/dθ = r·sin(165°) =
  0.32 mm/°); with the ±5° dtheta clamp the achievable chassis tilt is only
  ~0.3-0.6°, NOT 10°. The setpoint is +10° but the realized tilt is small.
  To get real lean, lower prep angle or raise the dtheta clamp (TODO/open).
- **PREP mass measurement (A4qq):** while sweeping through sin(θ)>0.7,
  sample tau_fb/(g·r·sinθ) per leg → measure on-board load (empty vs rider)
  → seed impedance, so FFW is accurate for the rest of the climb.
- PREP→DETECT when smoothstep done (alpha≥1) AND leg within prep_tolerance.

### Step 3 — front DETECT (FL/FR step-contact detection) [phase DETECT]
- FL/FR hold at prep angle (Kp=200 RIGID, A4ss) so step-contact force shows
  up as a clean torque spike instead of letting the leg yield.
- Residual = tau_fb − adaptive_gravity (A4oo). In steady state ≈ 0
  regardless of rider weight; spikes on real contact. Detection: deviation
  from LPF baseline > torque_res_threshold for detect_confirm_s, while leg
  velocity < detect_settle_omega.
- **ISSUE — turning false-trigger:** a yaw maneuver differentially loads the
  eccentric legs → torque residual mimics step contact. **Fix (A4ad):**
  `setDetectInhibit(true)` whenever the right-stick (rotation) is deflected
  past deadzone → all detection suppressed while turning. Detect only when
  driving (nearly) straight.
- Contact confirmed → FL/FR enter CLIMBING.

### Step 4a — front CLIMBING (kinematic step pivot) [phase CLIMBING]
- β integrates at `climb_omega`=0.8 rad/s (A4yy), ramped in via a 0.5 s
  smoothstep at entry (A4ww, kills the omega step-on jerk). θ from the
  constraint `cos(θ)=(R+L−h−R·sinβ)/L`; motor target = 180−θ. Flat PD
  Kp=80/Kd=4 follows.
- Wheel speed capped to chassis-matching rate × `climb_wheel_speed_ratio`
  (default 2.0, for joystick assist), hard-ceilinged at 25 RPM (A4xx/A4zz)
  → wheel never outruns the chassis kinematic forward velocity (no slip
  runaway) and never exceeds ~1/4 walking pace (passenger safety).
- Pitch held at +10° nose-up throughout front climb.

### Step 4b — front COMPLETE → nose-down lean → back DETECT
- FL/FR reach β=90° (or θ_end) → COMPLETE, hold at end-climb pose (front
  wheels now on top of step).
- **Re-tilt nose-DOWN −3° (lean forward, A4tt `climb_pitch_back_deg=-3`):**
  shifts CoM forward, reducing back-wheel pressure for easier back pivot.
  Optionally `climb_back_lift_offset_deg` (A4ab) directly biases the BL/BR
  hold angle. (Same geometric caveat applies near 165°.)
- **ISSUE — back legs near-stall during front trigger:** when the robot
  hits the step, it decelerates; that impulse plus the whole FL/FR CLIMBING
  trajectory motion loads the (essentially stalled) back legs, faking a
  step-contact residual on BL/BR. **Fix (A4ac + A4yy):**
    - BL/BR DETECT→CLIMBING gated until BOTH FL+FR are COMPLETE (not just
      climbing) — removes the entire FL/FR-climbing window of vulnerability.
    - Plus a `back_settle_s`=1 s delay after that, during which BL/BR
      baselines are snap-reset and re-converged via fast LPF.
    - Plus the A4ad turning inhibit.
- After settle, BL/BR detect their own step contact (user drives forward) →
  BL/BR CLIMBING → COMPLETE. All four COMPLETE → pitch returns to 0
  (level), climb done.

### Exit — HOMING_OUT
- Switching out of CLIMBING is intercepted: legs smoothstep back to 0°
  (ES-style, A4ee) before the actual mode change, so no leg is left near
  the seam.

### Open items / tuning knobs (Ozone `dbg_ctrl` unless noted)
- `climb_pitch_front_deg`=10, `climb_pitch_back_deg`=-3, `climb_pitch_lpf_alpha`
- `climb_omega`=0.8, `climb_ramp_s`=0.5 (config), `climb_wheel_speed_ratio`=2.0
- `torque_res_threshold`, `detect_confirm_s`(cfg), `detect_settle_omega`(cfg)
- `back_settle_s`(cfg)=1.0, `climb_back_lift_offset_deg`=0
- **Geometric pitch authority** at extended leg angles is the main
  limitation on Steps 2 & 4b: meaningful CoM shift needs either a lower
  prep angle (less reach) or a larger dtheta clamp (closer to seam). Decide
  on HW whether the small achievable tilt is sufficient.

---

## 1. Problem background

- Leg pose: `H = R - r·cos(θ)`. "Highest / climbing-prep" pose ≈ motor **±170°**,
  i.e. right at the encoder **±180° wrap seam**.
- The DM J10010L motor runs an **internal multi-turn absolute** position loop.
  When a position command crosses ±π, the DM may resolve it the long way and
  **accumulate a turn**; a later "return to 0°" then unwinds 1+ turns → bob.
- Old climbing code drove the leg with a **velocity command from shortest-path
  wrapped error** (`Pos_KP=0`, `Vel_KD` only). Near the seam the shortest-path
  error flips sign, so legs went the wrong way / inconsistent direction
  (observed: FL commanded +170 but settled −170; FR direction unstable).
- `HOMING_OUT` "ramp every leg back to 0° before any mode switch" was a
  **band-aid**, not acceptable: any accumulated turns unwind through it → bob.

### Per-leg facts observed (for reference)
- `bending_direction` (Robot_Config.cpp): FL=−1, FR=+1, BL=+1, BR=−1.
- `climb_sign` currently `{FL:+1, FR:−1, BL:+1, BR:+1}` (FL was flipped by user).
- A pure sign flip cannot create a *magnitude* offset → BR's −142° (vs ~166°)
  was NOT a sign issue; at that snapshot BR was almost certainly NOT in a
  climbing direct-control phase (back legs only start after both fronts
  COMPLETE), so it was in the normal `Set_Leg_Height` pipeline governed by
  `bending_direction`. Re-evaluate per-leg `climb_sign` empirically AFTER the
  direction mechanism is fixed (it now actually takes effect).

---

## 2. Target architecture — the real fix

**Maintain a continuous (unwrapped) leg angle in software and command the
nearest 360°-equivalent target; drive the leg with a single computed-torque law
sent as FFW only (`Pos_KP = Vel_KD = 0`) in ALL modes.**

Why this is safe & consistent:
1. We own the turn-resolution (software continuous angle), not the DM. With
   `Pos_KP=0` the DM never does position resolution → it can't unwind.
2. `H` is 360°-periodic, so `NearestEquivalentTarget()` always sends the leg the
   short way to an equal-height pose → no multi-turn motion ever.
3. Everything is one continuous torque law (no velocity↔position mode switch),
   so there is no switch discontinuity. PREP/hold → `ω_des=0`, the PD spring +
   gravity FFW holds; CLIMBING → `ω_des` = trajectory rate.
4. All feedback (pos + vel) is motor telemetry in consistent units. Only cost
   vs. the motor's internal loop is the 500 Hz software rate (acceptable; COMFORT
   already runs impedance at 500 Hz).

Control law (per leg, per tick) — **speed-limited software velocity loop**:
```
target_cont = NearestEquivalentTarget(angle_cmd_deg)        // wrap-free
err_rad     = deg2rad(target_cont - theta_continuous)
omega_cmd   = clamp(kp_pos*err_rad + omega_ff, ±omega_max)   // SPEED LIMIT here
omega_fb    = LPF(Get_LegVelocity())                         // rad/s, alpha=0.3
tau         = Get_LegGravityTorque()
            + clamp(kd_vel*(omega_cmd - omega_fb), ±tau_max)
Set_Leg_Target(Get_LegAngleWrapped(), 0, tau, Pos_KP=0, Vel_KD=0)
```
The `omega_max` clamp is essential: a plain position-PD would slam the leg on a
large step error (PREP 0→±170) — unsafe for the passenger AND the resulting
drive torque would swamp step detection (the torque shows up in the
`residual = torque - gravity` signal). Bounding speed keeps motion gentle and
the residual clean.
- Torque sign is correct: HOMING with `Pos_KP>0` already holds correctly, so the
  DM's "+torque increases position" convention matches `+kp_tau*err` (negative
  feedback). FFW is added in the same frame.
- Position arg = current wrapped angle so `Execute_Leg_Control`'s slew-limiter
  state stays synced (ignored by the motor since `Pos_KP=0`).

### Mode transition safety
Once ALL modes use this law + continuous frame, there is no ±180 seam crossing
and no accumulated turns, so **`HOMING_OUT`/return-to-0 band-aid can be removed**
(A5). Until then it stays.

---

## 3. Phased plan

### Track A — control unification (safety-critical; do first, validate each)

- **A1 — DONE.** Non-breaking continuous-position infra in `Wheel_Leg`:
  - Renamed `Get_LegPosition()` → **`Get_LegAngleWrapped()`** (wrapped (−180,180]).
    All ~26 call sites updated (Chassis.cpp, Wheel_Leg.cpp/.hpp).
  - Added **`Get_LegAngleUnwrapped()`** (continuous, never wraps).
  - Added accumulator in `Execute_Leg_Control()` top: `leg_pos_continuous_ +=
    wrap180(fb - prev_fb)`; self-seeds; pure state, no behavior change. Members:
    `leg_pos_continuous_`, `prev_leg_pos_fb_`, `leg_cont_initialized_`.
  - Added **`NearestEquivalentTarget(target_deg)`** → continuous-frame target
    within ±180° of current continuous pos.
  - Naming rule: **`Wrapped`** = single-turn / jumps; **`Unwrapped`** = continuous / safe.

- **A2 — DONE.** Added `Wheel_Leg::Set_Leg_Torque_Track(target_deg, omega_ff,
  kp_pos, omega_max, kd_vel, tau_max)` implementing the speed-limited velocity
  loop in §2. Added member `leg_vel_filt_` (vel LPF, alpha=0.3). Non-breaking.

- **A3 — DONE in code, NEEDS HARDWARE VALIDATION.** Migrated CLIMBING:
  - `Climbing_Dynamics::Config`: removed `climb_pos_kp_vel`, `climb_omega_max`;
    added `climb_pos_kp=8 (1/s)`, `climb_omega_max=3 (rad/s, speed clamp)`,
    `climb_kd_vel=2 (Nm·s/rad)`, `climb_tau_max=20 (Nm)`.
  - Rewrote the climbing direct-control branch in `Chassis::handleClimbingMode`
    to call `Set_Leg_Torque_Track(...)`. Pitch-leveling offset (`dtheta_deg`)
    preserved. Removed the old shortest-path velocity code.
  - **Step-detection fix (the "leg too fast → false phase switch" bug):** the
    closed-loop drive torque during motion contaminates the
    `residual = torque - gravity` signal and false-triggered DETECT→CLIMBING.
    Two-part fix: (a) `climb_omega_max` bounds leg speed so motion torque stays
    small; (b) detection is **velocity-gated** — added `leg_vel_radps` to
    `LegClimbFeedback` (filled from `Get_LegVelocity()` in Chassis) and
    `Config::detect_settle_omega=0.4 rad/s`; DETECT only accepts a torque
    deviation while `|leg vel| < detect_settle_omega`.
  - **Validate:** low gains first. FL now 0→+170 (correct direction), FR stable,
    firm hold, no oscillation, no false phase switch during PREP motion, no
    unwind on PREP/CLIMBING/COMPLETE. Tune `climb_pos_kp / climb_omega_max /
    climb_kd_vel` via config. Re-check per-leg `climb_sign` (direction now
    actually takes effect).
  - **KNOWN (expected):** CLIMBING→other-mode transition still buggy — that is
    the not-yet-unified modes (fixed in A4), not a regression here.
  - **FL single-leg direction bug — diagnosed & fixed.** Diagnosed via the
    `DbgClimbTarget dbg_climb_tgt` instrumentation (see `Chassis.hpp` —
    per-leg arrays of `theta_unsigned`, `angle_cmd`, `angle_fb`, `pos_cont`).
    Data showed `angle_cmd[FL]=+180` and `angle_cmd[FR]=−180` — both saturated
    against the `[0,180]` clamp because pitch-leveling added +15° on top of
    `theta_unsigned=165`. **±180 is the wrap seam:** at exactly that target,
    `NearestEquivalentTarget` resolves differently depending on tiny HOMING
    residual in `pos_cont`, so legs whose residual is slightly positive vs.
    slightly negative end up driving toward OPPOSITE equivalents (`+180` vs
    `−180`). FR happened to resolve consistently (+190 cont); FL flipped to
    the negative side. **Fix:** in `Chassis::handleClimbingMode`, clamp
    `new_theta` to `[5, 175]` (5° seam margin) instead of `[0, 180]`, so
    `angle_cmd` is always at least 5° away from ±180. This keeps the wrap
    math's `diff` strictly inside (−180, 180) regardless of HOMING residual.
  - **Per-leg diagnostic struct (kept; useful for A4 too):** `DbgClimbTarget`
    in `Chassis.hpp`, externed as `dbg_climb_tgt`, filled in the climbing
    branch after each leg's `Set_Leg_Torque_Track`. Fields per leg (index
    FL=0,FR=1,BL=2,BR=3): `theta_unsigned[4]`, `angle_cmd[4]`, `angle_fb[4]`,
    `pos_cont[4]`. Compare across legs in Ozone — should match each other up
    to the climb_sign pattern and small leveling offsets.

- **A3c — IN PROGRESS (FL-slow vs FR).** After the seam fix, FL goes the
  correct direction (+170) but **moves visibly slower than FR** even though
  travel distance is identical. Software pipeline inspection found no per-leg
  asymmetry between FL and FR (climb_sign just flips sign, lev_signs pitch
  is `+1/+1` for FL/FR so leveling is identical magnitude, gravity comp uses
  even `cos(θ)`). To localize whether the asymmetry is software or motor/mech,
  added **TEMPORARY** per-leg diagnostics to `dbg_climb_tgt`:
    - `omega_cmd[4]` — clamped velocity setpoint (rad/s)
    - `omega_fb[4]` — filtered velocity feedback (rad/s, alpha=0.3)
    - `tau_total[4]` — final torque sent to motor (Nm, gravity + PD)

  Sourced from new TEMPORARY snapshot fields in `Wheel_Leg` (`tt_omega_cmd_`,
  `tt_tau_total_`) + reused `leg_vel_filt_`, exposed via `Get_TT_*` accessors.
  All marked TEMPORARY — remove in A5 once FL-slow is root-caused.

  Decision rule when reading Ozone during PREP:
    - If `tau_total[FL] ≈ tau_total[FR]` but `omega_fb[FL]` tracks `omega_cmd`
      worse than FR → hardware/mech (friction, cable tension, motor params).
    - If `tau_total[FL] < tau_total[FR]` (magnitude) → software bug upstream
      of the motor; trace from tau back through the pipeline.

- **A3d — Seam crossing from position-loop overshoot.** After A3c diagnostics
  hardware test, observed that FL traveled `0 -> 165 -> -165` — i.e. the leg
  correctly went the SHORT way to +165 but then OVERSHOT, crossed +180 into
  the wrap seam, and settled at -165 (= +195 cont). FR was clean
  `0 -> -165`. Root cause is the cascaded PD's underdamped response: with
  `kp_pos=8, kd_vel=2`, damping ratio zeta ~0.25 -> ~45% overshoot beyond the
  commanded target. The previous 5deg seam margin (clamp to +/-175) left no
  room for overshoot; commanded target +175 + ~20deg overshoot = +195 crosses
  +180. **Fix (two-part):**
  1. Tighter clamp: `new_theta` clamped to `[prep_theta_deg, 180-prep_theta_deg]`
     = `[15, 165]` by default. This is the user's stated "ideal 0->165"
     range, leaves 15deg of seam headroom for overshoot.
  2. Bump `climb_kd_vel` from 2.0 to 6.0 (Nm.s/rad). Drops overshoot from
     ~45% to ~20%, which combined with the 15deg headroom safely stays inside
     +/-180 during the transient. Higher kd_vel adds noise sensitivity but at
     6.0 the velocity-feedback LPF (alpha=0.3) handles it.

- **A3e — Synchronized PREP lift ramp (chassis wobble fix).** After A3d closed
  the seam-crossing issue, the four wheel-legs lifted to PREP at visibly
  DIFFERENT speeds (per-leg friction/load differences let the faster legs win
  the race to `omega_max`), tilting the chassis and wobbling the passenger.
  Identical software cannot equalise real-world physical differences, so the
  fix is to **drive all legs from a shared time-based master trajectory**
  instead of letting each race independently:
  - `Climbing_Dynamics::Config::prep_ramp_s = 1.5f` — duration of the
    synchronized lift.
  - `LegState::prep_ramp_t` — per-leg ramp clock, reset to 0 in `startClimb`.
  - PREP case now smoothsteps `target_theta_deg` from 0 to
    `180 - prep_theta_deg` over `prep_ramp_s`, with `target_omega` set to the
    derivative of the smoothstep so the velocity-loop FFW keeps the PD
    tracking the ramp tightly. PREP -> DETECT transition gated on
    `alpha >= 1.0 AND |current - prep| < prep_tolerance_deg`.
  - All four legs share `dt` and start `prep_ramp_t=0` in the same
    `startClimbAll` call -> lockstep lift. Slow legs no longer lag, fast legs
    no longer pull ahead. Max ramp velocity ~2.88 rad/s (just under
    `omega_max=3`), within all legs' capability.

- **A3f — All four legs in synchronized PREP.** After A3e, FL/FR lifted in
  lockstep but BL/BR went up MUCH faster -- because the climbing FSM only put
  FL/FR in PREP (`startClimbAll` started indices 0,1 only); BL/BR were IDLE in
  the climbing FSM, so they fell back to the normal `Set_Leg_Height` pipeline
  driven by `target_chassis_height_` and slewed at `HEIGHT_SLEW_PER_CYCLE
  = 0.2 m/s`. That rate finishes the lift in ~0.65 s while FL/FR's `prep_ramp_s
  = 1.5 s` ramp takes more than twice as long -> visible asymmetry, chassis
  wobble. **Fix:**
  - `startClimbAll()` now starts ALL FOUR legs in PREP, so they all share the
    same `prep_ramp_t` clock and the same smoothstep -> the chassis rises
    perfectly level.
  - Removed the bottom-of-`update()` "front-first auto-start" gate that used
    to fire `startClimbDirect` on BL/BR once both FL/FR reached COMPLETE -- no
    longer needed because BL/BR are already in the climbing FSM. They now
    just sit in DETECT after their PREP finishes, waiting for their own wheel
    to hit the step. **Front-first climbing sequence is still preserved** --
    enforced naturally by physics (back wheels are not on the step yet, so
    their DETECT torque-spike condition only fires later, after the chassis
    has driven forward).
  - `startClimbDirect` is now unused; will be deleted in A5 cleanup.

- **A3g — BR climb_sign corrected.** With all 4 legs now in PREP via the
  shared ramp (A3f), BR was observed driving to +120 instead of -120. Final
  `climb_sign` confirmed empirically: **`{FL:+1, FR:-1, BL:+1, BR:-1}`** --
  left-right mirror pattern. The earlier `{+1, -1, +1, +1}` was leftover from
  before BR ever participated in the climbing FSM (BR was on the normal
  pipeline back then so its climb_sign was effectively unused, and the value
  defaulted incorrectly).

- **A4d — ES->COMFORT transition: sudden-impact + empty-chassis roll
  divergence.** Two pre-existing bugs that A4a/b made more visible:
  1. **Sudden impact at the transition tick.** `Set_Mode` was assuming the
     leaving-ES Kp/Kd was 80/4 (the OLD ES motor-Kp position-hold value), but
     after A4a ES uses torque-track with no motor Kp; the effective stiffness
     is the cascade product `climb_pos_kp * climb_kd_vel = 8 * 6 = 48 Nm/rad`
     and damping `climb_kd_vel = 6 Nm.s/rad`. With the stale 80/4 starting
     point the leg saw a stiff jolt at the first COMFORT HOMING tick.
     **Fix:** `prev_kp = 48`, `prev_kd = 6` for the ES->COMFORT path -- HOMING
     now gently RAMPS DOWN to `COMFORT_HOMING_KP_END=30, KD_END=2` instead of
     down from 80.
  2. **Empty-chassis roll oscillation diverges.**
     `COMFORT_HOMING_CHASSIS_MASS_GUESS` was set to
     `(ROBOT_MASS - 4*LEG_MASS) + RIDER_MASS_kg` (~70-80 kg). When the robot
     is UNLOADED, FFW = `M_est * g * r * sin(theta)` is ~7x too large at the
     HOMING->RUN handoff -- legs over-actuate, body rises, IMU sees roll, the
     roll PID's correction excites the over-strong FFW further -> positive
     feedback before the `M_est` LPF (tau~1 s) can converge to the true mass.
     **Fix:** `COMFORT_HOMING_CHASSIS_MASS_GUESS = ROBOT_MASS_kg - 4*LEG_MASS_kg`
     (chassis only, no rider). Trade-off: with a rider on, there is a brief
     ~6-7 deg sag at HOMING that the LPF pulls up within ~1 s. This is
     **strictly safer** than divergence: brief droop is recoverable, an
     oscillating wheelchair is not. Future improvement candidates: detect
     load state via accel-z or button, OR temporarily boost LPF alpha
     during the first second of RUN.

- **A4e — M_est seed REVERTED back to LOADED.** A4d's reduction to unloaded
  chassis broke the loaded COMFORT case: legs lacked FFW to lift the rider,
  observed as "cannot reach target height, lacks force, wobbles". Reverted to
  `(ROBOT_MASS - 4*LEG_MASS) + RIDER_MASS_kg`. **Trade-off accepted:** empty-
  chassis ES->COMFORT may oscillate during the M_est LPF settle (~1 s); to be
  fixed via a different mechanism (faster early-RUN LPF, or load detection)
  in A4g. Under-seeding is unsafe (can't lift); over-seeding is uncomfortable
  but recoverable.

- **A4f — Climbing body-mass FFW added.** PREP pitch wobble (front/back legs
  rising at visibly DIFFERENT rates after A3e/f synced their timing) was
  caused by `Set_Leg_Torque_Track` adding only `Get_LegGravityTorque()`,
  which counts the 0.5 kg leg only and ignores body weight. Under load,
  front/back asymmetric load -> per-pair PD lag differs -> pitch oscillates.
  **Fix:** `Set_Leg_Torque_Track` signature extended with a `ffw_torque`
  parameter (replaces the internal `Get_LegGravityTorque()`). Climbing now
  computes
  `ffw = (M_chassis/4 + LEG_MASS_kg) * g * r * sin(angle_cmd)`
  using the same `COMFORT_HOMING_CHASSIS_MASS_GUESS` (loaded), so the legs
  get accurate sin-based gravity compensation throughout PREP/DETECT/CLIMB.
  ES passes `ffw = 0` (target at theta=0, sin=0 -> no FFW needed anyway).

- **A4h — Raised software tau_max to match DM hardware ceiling.** Loaded
  COMFORT could not lift / hold the rider after A4b. Root cause: the OLD
  motor-internal MIT loop was only bounded by the DM's hardware torque
  ceiling (200 Nm per host config); the first software port artificially
  clamped at 30 Nm, and the loaded case routinely needed 30-60 Nm
  (FFW ~13 Nm + impedance Kp~60 * err of a few deg = easily 30+). PD
  saturated -> legs sagged -> the same loop tried to track rider sway but
  could not -> "lacks force, wobbles" symptom. **Fix:**
  - 5-arg `Set_Leg_Height` (COMFORT RUN): `COMFORT_TAU_MAX 30 -> 200`.
  - COMFORT HOMING (`handleComfortMode`): `HOMING_TAU_MAX 30 -> 200`.
  - 200 Nm matches the DM hardware ceiling configured by the host -- the
    software now never restricts what the OLD MIT loop could deliver.

  **Design note on speed limiting under high tau_max** (per user direction):
  the PD law has speed control built in via the `Kd*(omega_ff - omega_fb)`
  term -- as the leg accelerates under `Kp*err`, `Kd*omega_fb` grows and
  opposes motion. This is the natural mechanism and we should NOT layer an
  artificial position-error clamp on top (an earlier draft did this; the user
  correctly noted it duplicates what Kd already provides). If a particular
  mode feels too "snappy" under high tau, the lever is `cv_base` /
  `mit_kd_max` in `Impedance_Controller::Config`, not a software-side speed
  clamp. The cascaded `Set_Leg_Torque_Track` (CLIMBING) is a different case:
  its omega_max bounds the SHARED trajectory speed across legs for sync,
  not a damping concern.

- **A4i — ES<->COMFORT transition tuning.** After A4h's tau_max raise, three
  remaining issues:
  1. **ES->COMFORT still has slight 顿挫** at the transition. Cause: the old
     `COMFORT_HOMING_FRAMES = 250` (0.5 s lift) implies a peak smoothstep
     velocity of ~4.7 rad/s -- brisk for a rider-on entry. **Fix:** raised to
     `500` (1.0 s lift, peak ~2.4 rad/s) -- gentle, still snappy enough.
  2. **COMFORT->ES descent too fast** -- ES was using climbing's
     `climb_omega_max = 3 rad/s`, so the ~90 deg drop took ~0.5 s. **Fix:**
     ES now uses its own local `ES_OMEGA_MAX = 1.5 rad/s` -> ~1 s descent,
     smoother for the passenger.
  3. **Empty-chassis roll oscillation** -- user-requested PID modification.
     `BODY_ROLL_PID_INT_LIMIT` reduced `1000 -> 100`. The old huge limit let
     `Ki` accumulate over the ~1 s M_est LPF settle window during empty
     ES->COMFORT, pushing roll command into OUT_LIMIT saturation and
     diverging. The 100 cap bounds the integral contribution to ~0.02 m of
     h_adj (Ki * INT_LIMIT), still enough to nudge out steady-state offset
     but no longer winds up under transient mass misestimation. **NOTE:** the
     real root cause (M_est slow to converge for empty) is still A4g
     territory; this is a palliative that bounds the WORST-CASE windup, not
     a complete fix.

- **A4j — Targeted fixes for the three remaining COMFORT complaints.**
  1. **HOMING -> RUN "卡顿" (velocity-loop -> impedance jolt).** User identified
     the transition point. The Kp ramp from `entry_kp` to full impedance Kp
     was running at `ramp_rate = 0.005 / cycle` -> 0.4 s. Slowed to
     `0.002 / cycle` -> 1.0 s. The leg now eases into impedance-style
     compliance instead of snapping.
  2. **COMFORT -> ES descent still too fast.** ES_OMEGA_MAX 1.5 -> 1.0 rad/s
     -> the ~90 deg drop takes ~1.6 s, matching the COMFORT HOMING lift
     duration. Mirror symmetry between entry and exit.
  3. **Empty-chassis roll oscillation -- ROOT CAUSE FIX (A4g closed).** Added
     a fast-LPF window to `Impedance_Controller`:
     - New config: `ffw_lpf_alpha_fast = 0.1f` (~30 ms tau) and
       `fast_lpf_duration_s = 1.5f`.
     - New state: `fast_lpf_remaining_s_`, reset on `reset()` to the
       configured duration, decremented by `dt` each update tick.
     - Mass-update LPF picks `ffw_lpf_alpha_fast` while the timer is > 0,
       else the normal slow `ffw_lpf_alpha = 0.01`.
     - With the loaded seed (~70-80 kg) and empty actual (~10 kg), M_est
       converges in ~100-300 ms instead of ~1 s. Mass_scale then collapses
       the body-PID gains before oscillation can build. The slow steady-
       state alpha is preserved for noise filtering once converged.

  Combined with the previous A4i changes (slower HOMING smoothstep, smaller
  roll PID INT_LIMIT), the ES<->COMFORT transition should now be smooth in
  both directions and stable on both empty and loaded chassis. If empty
  oscillation still appears, next levers are `BODY_PID_SCALE_ROLL` (1.6 ->
  1.2) or further shortening `fast_lpf_duration_s`.

- **A4k — COMFORT->ES feel + impedance damping bump.**
  1. **"失重感" at COMFORT->ES descent + asymmetric front-vs-back fall when
     rider leans forward.** Same root cause: ES handler was passing `ffw=0`,
     so once the leg started descending the only restoring torque was the
     velocity damping `kd*(omega_cmd - omega_fb)` -- gravity ripped the leg
     down faster than omega_max would suggest, especially on the heavier
     (rider-forward) front legs. **Fix:** ES descent now sets
     `ffw = (M_est/4 + LEG_MASS) * g * r * sin(theta_now)` per leg, using
     the live impedance M_est. With gravity fully cancelled, descent rate is
     now set by `ES_OMEGA_MAX` alone (1 rad/s) and is uniform across legs
     regardless of weight distribution.
  2. **A/X (mid-height) roll wobble vs Y (top) robust.** At mid heights the
     impedance Kp is at its peak (sin² maxes around theta=90), making the
     leg/body coupling stiffest -- exactly where the body PID was most able
     to excite ringing. Past mode could not damp enough because the OLD
     motor-MIT Kd was hardware-capped at 5. With the unified software path
     there is NO hardware Kd ceiling -- `kd*v` is just a software multiplier.
     **Fix:**
     - `cv_base 1500 -> 3000` (doubled virtual damping coefficient).
     - `mit_kd_max 5 -> 10` (software cap; documented that old "MIT
       hardware" reason no longer applies).
     - Peak Kd at theta=90 now 10 Nm.s/rad (was 5). zeta ~2.2 loaded, ~7
       unloaded -- heavily overdamped, kills the wobble per user's
       "可以继续增大阻尼抑制" request.

- **A4l — Per-leg torque snapshot for symmetric ES descent.** With A4k's
  M_est-based uniform FFW, EVEN load (rider centred) descends well, but
  off-centre rider revealed the next layer:
  - uniform FFW = M_est/4 per leg
  - rider on back -> back legs need MORE support than M_est/4
  - rider on front -> front legs need MORE
  In whichever direction is "lighter than M_est/4", the FFW OVER-supports,
  the leg can't descend, and the asymmetric drop returns (just opposite of
  the original ffw=0 case).
  **Fix:** snapshot each leg's actual motor torque at the COMFORT->ES
  transition, scale by `sin(theta_now)/sin(theta_entry)` during descent. The
  snapshot reflects the impedance-shaped per-leg torque distribution that
  COMFORT had been running, which DOES capture the rider weight asymmetry
  (impedance pushed back-side legs harder when rider sat back). Scaling
  by sin tracks the changing pose as the leg descends. Gravity now cancels
  exactly per leg -> descent velocity is set by `Kd*(omega_cmd - omega_fb)`
  alone -> ALL four legs descend in lockstep regardless of weight
  distribution.
  - Members: `es_entry_tau_[4]`, `es_entry_sin_[4]`, `es_snapshot_valid_`.
  - Set in `Set_Mode` when entering ES from COMFORT (other source states
    have no impedance history -> fall back to A4k's uniform M_est/4 ffw).
  - Used in `handleEnergySaving` ffw computation. Snapshot sin clamped to
    ±0.3 to guard against the theta~0/pi singularity (won't fire in
    practice since COMFORT pose is ~theta=90).

- **A4m — ES architectural rewrite: "COMFORT pinned at lowest".** Per user
  direction "用严格速度环以及ffw进行控制, 而不是用阻尼下降". The previous
  `Set_Leg_Torque_Track` + `omega_max` clamp + ffw approach was damping-based:
  the velocity loop only BRAKED against gravity rather than tracking a real
  velocity reference. Uniform M_est/4 ffw under-supported heavy-loaded legs
  and over-supported light-loaded legs -> asymmetric descent.
  **Fix:** ES now reuses the COMFORT control law entirely:
  ```
  target_height_setpoint_ = h_min_   // pin the height target at the lowest pose
  impedance_.update(...)             // keep per-leg Kp/Kd/FFW live
  executeBodyControlImpedance(cmd)   // same path COMFORT uses on button height switches
  ```
  COMFORT's button-driven height changes were already "丝滑" (per user) for
  the same reason: `slewTargetHeight` produces a jerk-limited height
  profile + a real `height_slew_rate_` velocity FFW, fed to each leg via
  `Set_Leg_Height(h, v, kp_imp, kd_imp, ffw_imp)`. Inside Set_Leg_Height
  this becomes `Set_Leg_PD_Torque` -> `tau = Kp*err + Kd*(v_ff - v_fb) + ffw`.
  With impedance's per-leg ffw and the v_ff term, all four legs track the
  slewed target uniformly regardless of rider weight distribution. Descent
  velocity is the slew rate, not "whatever gravity wins against Kd*omega".
  - Stale members `es_entry_tau_[4]`, `es_entry_sin_[4]`, `es_snapshot_valid_`
    are now unused; A5 will delete them.
  - Descent speed governed by `slewTargetHeight`'s `rate_down =
    HEIGHT_SLEW_PER_CYCLE * 0.5`. From mid COMFORT height to h_min (~0.064 m
    range) takes ~0.65 s + ~0.15 s LPF tail ~0.8 s. If user wants exact
    symmetry with the 1 s lift, tune `rate_down` factor here later.

- **A4n — KNOWN OPEN: climbing PREP per-leg sync under rider.** After A3f,
  prep_ramp_t is shared across legs so the COMMANDED target is identical, but
  per-leg ACTUAL tracking lags differ under rider load asymmetry (heavier
  leg's PD can't keep up with the ramp; lighter leg may even overshoot).
  Same root cause as the ES asymmetric-descent that A4m just solved: uniform
  M_est/4 ffw can't compensate per-leg load distribution. The ES fix
  (impedance-shaped per-leg ffw via Kp*err closed loop in COMFORT) is not
  available in climbing because we usually enter CLIMBING from IDLE/ES, not
  COMFORT -- no Kp*err history to inherit. Two paths to consider:
  - **Slow ramp / boost damping:** `prep_ramp_s 1.5 -> 3.0 s`, +
    `climb_kd_vel 6 -> 10`. Doesn't fix asymmetry mathematically but gives
    each leg more time to converge -> visible synchronization tightens.
  - **Pre-PREP impedance settle:** insert a brief (~0.5 s) impedance phase
    BEFORE the prep ramp where each leg holds at its current angle with
    impedance Kp*err loop closed. This lets impedance shape per-leg torques
    to match actual load; snapshot those torques and use as the per-leg ffw
    basis throughout PREP. Same idea as A4l's ES snapshot but earned within
    climbing.

- **A4m REVERTED, A4o — Simple smoothstep-angle ES descent.** A4m's
  "COMFORT pinned at lowest" approach JUMPED on entry: feeding the
  impedance/leveling machinery target_height_setpoint_=h_min when the
  previous state's target_chassis_height_ was different (and leg angle
  unrelated) produced a step in commanded leg target -> Kp*err burst ->
  visible jump. **Per user direction "简单的速度和位置闭环就好了, 主打稳
  定 smooth":** scrapped the impedance reuse, dropped the snapshot scheme,
  and implemented the simplest correct thing -- a smoothstep angle ramp.
  ```
  on entry:  energy_homing_start_angle_[i] = current angle      // captured in Set_Mode
             energy_homing_ticks_ = 0
  each tick: alpha = ticks / FRAMES                              // 0 -> 1 over 1 s
             s     = alpha*alpha*(3-2*alpha)                     // smoothstep
             target_now = start * (1 - s)                        // from start -> 0
             omega_ff   = -start * d(s)/dt                        // matched velocity FFW
             ffw_grav   = (M_est/4 + LEG_MASS) * g * r * sin(now) // gravity comp
             Set_Leg_PD_Torque(target_now, omega_ff,
                               ES_KP=50, ES_KD=8, ffw_grav, 200)
  ```
  Why no jump: target STARTS at the leg's actual entry angle, so err=0 at
  tick 0 -> no Kp*err burst. The smoothstep ramps target smoothly to 0 with
  zero velocity at both endpoints (matched by omega_ff also zero at
  endpoints), so the start and end of descent are jerk-free. Gravity FFW
  cancels per-leg gravity using the M_est carried over from COMFORT.
  - `ENERGY_HOMING_FRAMES 400 -> 500` (1 s) for symmetry with the
    COMFORT_HOMING_FRAMES=500 lift.
  - Stale snapshot capture removed from Set_Mode. The members
    `es_entry_tau_[4]/es_entry_sin_[4]/es_snapshot_valid_` are now unused
    (will delete in A5).

- **A4p — COMFORT HOLD phase + symmetric slew rate.**
  1. **"阶段性" between lift and impedance.** Even with smooth Kp/Kd
     continuity at HOMING->RUN handoff, impedance + body-PID engagement was
     perceptible immediately after the lift. User wants the lift to FULLY
     SETTLE before impedance kicks in. **Fix:** added a fixed-PD HOLD phase
     after the smoothstep: `COMFORT_HOLD_FRAMES = 250` (0.5 s). During the
     hold the smoothstep alpha is already clamped at 1 (target stays at
     `COMFORT_HOMING_THETA`), Kp/Kd stay at `KP_END/KD_END`, ffw stays on
     the open-loop sin-based form. Transition to RUN only when
     `ticks >= FRAMES + HOLD_FRAMES`. Then impedance ramp_alpha (still
     ramp_rate = 0.002, ~1 s) smoothly takes over with the leg fully
     stationary at target. Total time from button press to full impedance:
     1 s lift + 0.5 s hold + 1 s impedance ramp = ~2.5 s. Stable, no
     perceptible "stage" change.
  2. **COMFORT button-height up too fast (motor strain).** `rate_up` was at
     full `HEIGHT_SLEW_PER_CYCLE = 0.0004 m/cycle` -> 0.2 m/s while
     `rate_down` was 0.5x. The asymmetric full-rate up under load stressed
     the motors. **Fix:** `rate_up = HEIGHT_SLEW_PER_CYCLE * 0.5f` (matches
     `rate_down`). Both directions now 0.1 m/s. In-COMFORT height changes
     take ~1.3 s for full 0.13 m range. Quieter, kinder to the motors.

- **A4q — Body PID active during COMFORT HOMING.** Even after A4p's HOLD
  phase eliminated the impedance-engagement edge, an off-centre rider still
  felt a "再抬一下" at HOMING -> RUN. Root cause: HOMING commanded all four
  legs to the SAME angle (uniform smoothstep). With an off-centre load the
  per-leg PD's Kp*err couldn't perfectly equalise heights -> chassis arrived
  TILTED at end of HOMING. RUN then started body PID from rest, which
  proceeded to LEVEL the tilted chassis -> visible secondary lift on the
  heavy side. **Fix:** run roll/pitch body PID DURING HOMING (and HOLD),
  scaled by the smoothstep progress `s`:
  ```
  roll_h_adj_hom  = roll_pid(0, roll_lpf)  * BODY_PID_SCALE_ROLL  * s
  pitch_h_adj_hom = pitch_pid(0, pitch_lpf) * BODY_PID_SCALE_PITCH * s
  per leg: cmd_deg += dtheta_from_per_leg_h_adj   // via dH = r*sin*dtheta
  ```
  At s=0 (lift start) the PID contribution is 0 -> no jump on entry. As s
  grows the PID effect ramps in, levelling the chassis CONTINUOUSLY through
  the lift. By s=1 (lift complete + HOLD) the body is already level and
  RUN's impedance handoff has nothing to correct. The lev_signs and
  BODY_PID_SCALE_* are the same as RUN, so a tilt correction during HOMING
  is mathematically identical to one during RUN. Independent LPF state
  (`roll_lpf_homing`, `pitch_lpf_homing`) seeded from `chassis_roll_/pitch_`
  on tick 0 so the filter doesn't start at 0 and create a synthetic error.

- **A4r ATTEMPTED, REVERTED.** Tried to fix COMFORT-entry "顶屁股" by
  measuring chassis+rider mass at HOMING end (via per-leg motor torque) and
  seeding M_est with it. **Why it fails:** the measurement is circular under
  the unified torque path. Motor torque = software-computed `tau =
  Kp*err + Kd*derr + FFW`. At HOLD steady state, err≈0 and derr≈0, so
  tau ≈ FFW = M_guess-based. Reading tau back via
  `tau_i / (g*r*sin_i)` recovers M_guess, NOT the true load. No new info.
  Need a non-circular signal (test pulse during HOMING, accel-based
  weighing, etc.) for a real fix. Deferred to a future pass.

- **A4s ATTEMPTED, REVERTED.** Smoothstep ramp on climbing pitch_setpoint
  (0 -> ±`climb_pitch_bias` over 1.5 s) caused hardware to "突然单边挑起"
  (sudden one-side lift) -- very dangerous. Two suspected root causes
  (still to investigate before a redesign):
  (a) **Sin singularity at PREP start.** After A3f, `theta_unsigned`
      smoothsteps from 0 to ~165 over `prep_ramp_s`. The climbing pitch-
      leveling formula `dtheta = -dh/(r*sin(theta_unsigned))` divides by
      sin which is clamped at 0.15 near theta=0. Any non-zero
      `pitch_h_adj` early in PREP gets amplified to a dtheta ≥ 50° (clip
      cap) -> huge instant leg motion. The smoothstep ramp on pitch_setpoint
      doesn't help if the resulting pitch_h_adj after PID still produces
      a large dh / small sin division.
  (b) **Front -> back pitch_setpoint switch.** When the last front leg
      reaches COMPLETE, `front_active` becomes false and `back_active`
      stays true -> setpoint flips from -bias to +bias (a 6° step at
      bias=3°). The ramp only affected entry; the front->back switch
      stays abrupt. Pre-existing issue, but the ramp made it more
      visible. Need either a separate front->back transition ramp or a
      single unified setpoint trajectory.
  Deferred.

- **A4v — ES->COMFORT transition-tick torque-spike fix.** User observed
  "状态切换不 consist, 那一下 impact 超过电机爆发扭矩, 电机抖动" -- a
  transient at the SWITCHING MOMENT (not during the lift later) exceeding
  motor burst torque. Two contributing sources found and addressed:
  1. **Kp jump at HOMING entry.** `comfort_homing_kp_start_` was 48 (matching
     ES's effective cascade Kp). At HOMING tick 0 with even a couple of
     degrees of residual angular err (sensor noise, post-A4o settle), the
     `Kp*err` term could push 2-4 Nm INSTANTLY, plus body-PID and fast-LPF
     spike contributions, stacking into a burst exceeding the motor limit.
     **Fix:** drop `prev_kp = 10`, `prev_kd = 2` for ES->COMFORT entry. At
     theta~0 (folded pose) legs bear no chassis load, so soft Kp is safe --
     there's nothing to support. The ramp then climbs to KP_END=30 as legs
     reach loading angles. First-tick spike eliminated.
  2. **Wheel velocity step.** COMFORT HOMING was forcing `Set_Wheel_Target(0)`
     while ES had the wheels at joystick velocity. If the rider was driving
     forward when pressing the mode button, wheels saw an instant
     `joystick_RPM -> 0` step -> HT internal velocity loop braked hard ->
     chassis decelerated -> rider's weight shifted forward -> front legs got
     a reaction-torque spike. **Fix:** HOMING now tracks joystick wheel
     velocity (same as ES), with NO `Add_Wheel_Compensation` (the original
     reason "wheels at 0 during HOMING" was wheel-comp-driven creep, not the
     joystick RPM itself). Wheel velocity is now continuous through the
     ES->COMFORT boundary, so legs no longer feel a wheel-brake reaction.

- **A4w — Removed `pid_gate` discontinuity at HOMING -> RUN.** User clarified
  the BIG IMPACT was NOT at the button-press tick but at the
  "switch-to-impedance-control" moment (i.e. HOMING+HOLD -> RUN handoff).
  Root cause: `executeBodyControlImpedance` was multiplying body PID outputs
  by `pid_gate = impedance_.getRampAlpha()`, which is 0 at RUN start and
  ramps to 1 over ~1 s. After A4q (body PID active during HOMING gated by
  smoothstep `s`), by HOLD's end PID is at FULL strength holding the body
  level. RUN tick 1 then forces `pid_gate=0`, dropping the leveling forces
  to zero IN ONE TICK -- the chassis (e.g. with off-centre rider) suddenly
  loses the per-leg support being supplied by the PID, the heavier side
  falls, the lighter side rises -> that's the IMPACT.
  **Fix:** removed the `pid_gate` multiplication. PID is now continuously
  at full strength across HOMING (via A4q's smoothstep gating) + HOLD + RUN
  -- no discontinuity. The historical reason for `pid_gate` (prevent ±0.08 m
  legs-slammed explosion at entry @ θ≈0 when ES held Pos_KP=80) is no
  longer relevant -- A4q's smoothstep already prevents that.

- **A4x — Three targeted tuning passes (all leg-side, no wheel changes).**
  1. **ES position loop stiffer.** Differential turning loaded the legs
     sideways through the eccentric wheel coupling; the previous `ES_KP=50,
     ES_KD=8` let the legs drift back-and-forth under that reaction torque
     (rider observed wheels being "扯前后" during yaw). **Fix:** `ES_KP =
     120`, `ES_KD = 12`. Holds theta=0 firmly through yaw transients.
  2. **Climbing PREP four-leg sync (A4n addressed).** Rider load asymmetry
     made the synchronized smoothstep visibly desynchronized at
     `prep_ramp_s=1.5 s` -- front legs reached PREP target ~0.3 s before
     back legs (or vice versa depending on weight distribution), the
     chassis tilted forward/back during the lift. **Fix:** slow the lift
     to `prep_ramp_s = 3.0 s` so the lagging leg has time to catch up
     while the leading leg waits at the slowly ramping target; AND bump
     `climb_kd_vel = 6 -> 12` for tighter per-leg velocity tracking on the
     ramp. The pair that's heavier still lags slightly, but within a few
     degrees (Kd*omega_err scales linearly with the higher kd_vel) so the
     chassis stays close to level throughout.
  3. **Climb-exit return-to-0 gentler.** `CLIMB_HOMING_FRAMES 400 -> 1000`
     (0.8 s -> 2.0 s). Climbing exit covers a much larger range (up to
     ±165°) than COMFORT's smoothstep, so it needs more time to feel
     symmetric to the COMFORT->ES descent. Affects HOMING_IN as well --
     entry from a high-pose source state (COMFORT theta~90 -> 0) is also
     gentler. Entry from ES (theta~0 -> 0) just sits in place for the 2 s
     window, harmless but a minor delay; can tune separately if needed.

- **A4y — Climbing pitch-leveling SIGN BUG fixed (long-standing).**
  Re-analysing the "front legs first, back legs later" symptom revealed the
  climbing-branch pitch-leveling formula has the wrong sign:
  ```
  // BEFORE (wrong):
  dtheta_deg = -dh / (r * sin_thu) * (180/pi)
  ```
  The comment said it was derived from `H = R + r·cos(θ)` (the OLD height
  convention where θ=0 is highest). But motor's actual convention is
  `H = R - r·cos(θ_motor)` (NEW, θ=0 is lowest). dH/dθ has OPPOSITE sign
  between the two conventions. With the leading `-`, the formula made
  `pitch_h_adj < 0` (PID wanting nose down) push FL/FR HIGHER and BL/BR
  LOWER -- i.e. body NOSE UP, the EXACT OPPOSITE of intent. PID error grew
  rather than shrank -> formula AMPLIFIED any pitch error -> "front legs
  reach PREP target first, back legs much later" symptom.
  **Fix:** drop the leading `-`. Now:
  ```
  dtheta_deg = dh / (r * sin_thu) * (180/pi)
  ```
  For PID wanting nose down: FL/FR get LOWER target, BL/BR get HIGHER target
  -> body actually tilts nose down -> error shrinks. Matches the COMFORT
  convention's lev_signs behavior. This should fix the front-back desync.

- **A4z — Heavy roll damping bump (third pass).** User still observed roll
  divergence after A4k's cv_base=3000 and mit_kd_max=10. Bumped further:
  - `cv_base 3000 -> 5000` (impedance virtual damping coefficient)
  - `mit_kd_max 10 -> 15` (no motor-side ceiling under unified torque path)
  - `BODY_GYRO_FF_GAIN_ROLL 0.0035 -> 0.007` (direct body-rate damping --
    faster than leg-Kd's indirect path)
  Peak leg Kd at theta=90 is now ~15 Nm.s/rad (zeta ~3.4 loaded). Combined
  with doubled gyro-FF, the roll axis should be strongly overdamped.
  Trade-off: sluggish response to LEGITIMATE roll disturbances (cobblestones,
  ramp transitions), but no divergence.

- **A4aa — PREP-entry leveling progress gate.** After A4y fixed the climbing
  pitch-leveling sign, a NEW issue surfaced: "PREP 开始时四个 leg 电机发抖，
  向前小蹬，再升起". Root cause: at PREP start `theta_unsigned~0`, the
  pitch-leveling formula `dh / (r·sinθ)` has its `sinθ` clipped to 0.15
  (singularity guard) -- so any tiny `pitch_h_adj` blows up to a ±50° dtheta.
  The `new_theta ∈ [prep_margin, 180-prep_margin]` clamp then holds the
  commanded angle at 15° even though smoothstep target is still ~0°. The
  leg gets pulled hard to +15° (jitter) for ~0.5 s until smoothstep advances
  past the sin-clip threshold and the clamp releases (sudden release ->
  forward kick).
  **Fix:** multiply `dh` by `ramp_progress = theta_unsigned / (180 -
  prep_theta_deg)`. At PREP start (theta_unsigned~0), ramp_progress~0,
  leveling output 0 -> no amplification near the sin singularity. As the
  smoothstep advances, ramp_progress grows to 1, leveling fully engages
  before legs reach top of PREP. Smooth lift, no jitter, no kick.

- **A4bb — COMFORT roll oscillation: lower body-PID aggressiveness.** After
  A4z's heavy leg-side damping (cv_base=5000, mit_kd_max=15), roll was still
  unstable in COMFORT -- which means leg-side Kd is no longer the bottleneck.
  The remaining instability source: BODY_PID_SCALE_ROLL=1.6 made the body
  PID output large for any small roll error, and the now-stiff leg side
  responded aggressively -> overshoot -> PID reversed -> sustained
  oscillation. **Fix:**
  - `BODY_PID_SCALE_ROLL 1.6 -> 1.0` -- PID is less aggressive overall.
  - `BODY_ROLL_PID_KD 0.00012 -> 0.0004` (3x) -- body-PID's own derivative
    term provides direct chassis-roll-rate damping, which is faster than
    the indirect path through leg dynamics.
  The system was overdamped on the LEG side but UNDER-damped at the
  body-PID layer -- moving damping from the wrong place to the right place.

- **A4ax — Per-leg smoothstep authorities for COMPLETE-gate AND offsets.**
  User feedback after A4aw: "FL FR complete 之后还是会出现这个突然类似调整
  pitch 一样的瞬间响应 很僵硬的位置控制 没有一点平滑，FL FR 突然变矮
  再突然变高". A4aw only smoothed the BL/BR-CLIMBING dynamics dampening,
  but TWO step changes at the per-leg CLIMBING->COMPLETE transition were
  still un-smoothed:
    1. **`phase_gate` 0->1 step (A4uu)**: the body-PID dtheta was binary
       gated -- the instant the leg entered COMPLETE, full PID dtheta hit
       the leg as an impulse. With Kp=200, even 5 deg of dtheta error =
       17 Nm motor pulse -> "类似调整pitch一样的瞬间响应".
    2. **`climb_front_drop_deg` 0->15 deg step (A4af)**: the front leg's
       direct angle offset was applied as a binary on/off. At
       CLIMBING->COMPLETE entry, target leg angle dropped 15 deg in one
       tick = "突然变矮". At back-all-COMPLETE release, it snapped back =
       "再突然变高". Same for back_extend (A4av) on BL/BR.
  Fix: TWO per-leg smoothstep authorities, ramped over `climb_dtheta_ramp_s`
  (same tunable as A4aw, default 0.5 s).
    * `phase_complete_authority_[4]`: target = 1 if leg in COMPLETE else
      0. Smoothstep 0->1 on COMPLETE entry. Stays 1 (legs don't leave
      COMPLETE during a climb). Multiplies `phase_gate` -> PID dtheta
      eases in over 0.5 s after CLIMBING ends.
    * `leg_offset_authority_[4]`: target = 1 when the leg's direct angle
      offset (front_drop / back_extend) should apply, else 0. Smoothstep
      handles BOTH entry (offset eases in over 0.5 s as the leg becomes
      eligible) AND exit (offset eases out over 0.5 s when the climb
      finishes / conditions cease).
  Application sites changed: `phase_gate` now reads from
  phase_complete_authority instead of the binary check; front_drop and
  back_extend are now multiplied by leg_offset_authority instead of
  gated by a binary if. The previous condition logic is now redundant
  (encoded into the authority's target computation) and removed.
  Edge cases handled via the start-from-current-value reset pattern
  (same as A4aw): mid-ramp interrupts (rare, e.g. quick mode-switch)
  restart the ramp from the current value, not from 0/1, so the leg
  never visibly snaps.
  Tunable: increase `climb_dtheta_ramp_s` (Ozone) for even gentler
  transitions; decrease for snappier engagement. 0 disables smoothing
  (brings back the snap -- not recommended).
  Net effect: every climb-phase boundary that previously caused FL/FR
  to "突然变矮 再突然变高" now ramps smoothly. The leg feels deliberate
  and continuous, matching the PREP lift profile the user is comfortable
  with ("就和我进prep一样").

- **A4aw — Smoothstep-ramped FL/FR dtheta authority during BL/BR CLIMBING.**
  User feedback after A4av: "为什么在 FL FR complete 之后还会有明显的位置环
  介入，一下上 一下下 非常僵硬". Root cause: FL/FR is in COMPLETE, so A4uu's
  phase-gate ALLOWS body-PID dtheta. Meanwhile BL/BR's CLIMBING phase
  rotates beta 0->pi/2 over 2.5 s, which dynamically changes chassis
  pitch. Body PID sees pitch deviating from its setpoint and pumps
  correction dtheta into FL/FR's target. With Kp=200 (A4aq), each 1 deg
  of dtheta = ~3.5 Nm motor impulse -> visible position jerk + "rigid"
  feel. The PID is reacting to dynamics it shouldn't try to fight (the
  chassis pose during back-climb is determined by geometry, not by
  controller authority).
  Fix: gate FL/FR's dtheta by a smoothstep-ramped authority `[0..1]`.
    * Target = 0 when BL/BR is in CLIMBING phase
    * Target = 1 otherwise (full PID leveling restored once back-climb
      done, for static-pose body leveling)
    * Smoothstep ramp `climb_dtheta_ramp_s` (default 0.5 s) -- linear
      ramp would jerk the leg at edge transition; smoothstep matches the
      PREP lift profile user is comfortable with ("就和我进prep一样")
    * Per-tick state: authority value + transition start value + target +
      timer. Edge detection via target-changed -> reset timer & start.
      Mid-transition interrupts are handled cleanly (start from current
      value, ramp to new target over ramp_s).
    * Applied ONLY to FL/FR (i<2). BL/BR's dtheta already zeroed via
      A4uu's COMPLETE-only phase gate while they're in CLIMBING.
    * Authority multiplies `phase_gate` -> the dh -> dtheta_deg chain.
      Inherits the existing +/-15 deg clamp downstream.
  Effect: when BL/BR enters CLIMBING, FL/FR's PID-driven angle perturbations
  ramp out over 0.5 s -> leg sits still on its static target (theta_complete
  + climb_front_drop + A4av back_extend if applicable). When BL/BR all
  COMPLETE, PID ramps back in for normal body leveling.
  Open TODO: if even the static-target hold feels jerky from wheel-leg
  coupling, may need to also lower FL/FR Kp temporarily.

- **A4av — BL/BR direct angle extend mechanism (mirror of front drop).**
  User HW: detection now works (A4at+A4au) and BL/BR triggers cleanly,
  but the climb itself struggles -- "后轮会有打滑，前leg可能又会被往前憋" =
  back wheels slip during their CLIMBING phase, and FL/FR's rigid
  COMPLETE hold gets strained forward by the back-climb dynamics. User
  proposal: shift CoM by "back leg up + front leg down". The existing
  `climb_front_drop_deg = 15` covers half (front legs shorten -> chassis
  front drops). The other half is added as `climb_back_extend_deg`:
    * Direct angle offset on BL/BR motor (mirror of front drop, but
      ADDED instead of subtracted).
    * Applied throughout BL/BR's DETECT + CLIMBING + COMPLETE while
      FL/FR are both COMPLETE and BL/BR aren't yet both COMPLETE.
      Released once climb is fully done.
    * Default 0 (no behavior change); tune from Ozone.
    * Signed:
        - `> 0`: back motor angle larger -> back leg extends -> back
          rises -> nose-down -> CoM forward -> back UNLOADED (less
          weight, easier pivot, LESS grip). The "extending" interpretation.
        - `< 0`: back motor angle smaller -> back leg shortens -> back
          drops -> nose-up -> CoM backward -> back LOADED (more weight,
          harder pivot, MORE grip). The "loading-for-grip" interpretation.
  Trade-off depends on whether the slip is grip-limited (try negative)
  or load-limited (try positive). Geometric authority is weak at the
  starting 165 deg (sin(15deg)=0.26, 0.32 mm/deg) but grows through the
  CLIMBING sweep as the leg approaches 90 deg (sin -> 1.0). For CLIMBING
  phase the offset rides on top of the kinematic trajectory -- a small
  deviation from the pure beta-pivot path traded for chassis pose
  control. Clamps preserved: re-bounded to `[prep_margin, upper_clamp]`
  (= [15, 175] for back during this window) so the seam stays safe.
  Open question / TODO: if FL/FR strain persists after CoM tuning, may
  need to reduce FL/FR Kp during BL/BR CLIMBING to allow chassis
  rotation freely.

- **A4au — back_settle now triggers on FL/FR CLIMBING entry (not COMPLETE).**
  After A4at, the gate opened the instant FL/FR entered CLIMBING -- but
  the user's plot showed TWO peaks in BL/BR `wheel_drop` during a front
  climb:
    * **Peak 1 (FALSE, 0-500 ms post-FL-trigger):** the FL/FR climb-entry
      smoothstep (climb_ramp_s=0.5 s) ramps phi_w 0 -> 0.8 rad/s. The
      sudden phi_w change couples through the wheel-leg dynamics into a
      torque/RPM transient on BL/BR that looks identical to step contact.
    * **Peak 2 (REAL, ~1.5-2.5 s post-FL-trigger):** chassis has advanced
      ~3-4 cm forward via the climb trajectory; BL/BR wheels reach the
      step face and decelerate against it -- true step contact.
  A4at alone would false-trigger on Peak 1. A4ac's BOTH-COMPLETE trigger
  missed Peak 2 (gate opened ~3.5 s post-FL-trigger, after the LPF
  baseline had caught up and the signal was gone). Solution: keep A4at's
  CLIMBING-OR-COMPLETE gate, but trigger `back_settle` (1 s) on the
  CLIMBING-entry RISING EDGE instead of the COMPLETE edge. Settle blocks
  the 0-1 s window (skips Peak 1); BL/BR DETECT is then enabled for the
  rest of FL/FR's CLIMBING and catches Peak 2 cleanly. The CLIMBING-entry
  edge also serves as a logical baseline-reset point (the LPF now starts
  tracking the steady-state operating point of "FL/FR mid-climb,
  BL/BR holding at prep") rather than the pre-climb state. Variable
  `front_was_complete_` kept as-is for ABI/diff stability; comment notes
  its new semantics ("both front in CLIMBING-or-COMPLETE").

- **A4at — Relax front_gate from BOTH-COMPLETE to BOTH-CLIMBING-OR-COMPLETE.**
  User HW data with A4as diagnostics: strong BL/BR `wheel_drop` signals
  appear ~1.8 s after FL/FR transitions DETECT->CLIMBING, BUT `detect_allowed`
  for BL/BR doesn't open until ~3.5 s after FL/FR trigger (= 2.5 s FL/FR
  CLIMBING duration + 1 s `back_settle`). By the time the gate opens, the
  LPF baseline has caught up and the signal is gone -- auto-detect can't
  fire on real step contact. Physics: during FL/FR's CLIMBING, the chassis
  advances ~3-4 cm forward (kinematic forward velocity = R*cos(beta)*phi_w
  integrated over the climb); after ~1.8 s, the back wheels roll into the
  step face -> real BL/BR step contact. Fix: front_gate now passes when
  BOTH front legs are in CLIMBING OR COMPLETE (was: BOTH COMPLETE).
  `back_settle` still applies on COMPLETE transition (no-op if BL/BR
  already triggered during CLIMBING; otherwise existing 1 s deceleration-
  impulse delay). Trade-off: during the first ~0.5 s of FL/FR CLIMBING
  (the smoothstep ramp-up), wheel-leg coupling transients could mimic
  step contact -- mitigated by the combined-score threshold (wheel_drop
  needs >= 12 RPM, well above coupling noise; t_score = 0 because the
  back legs are at rest with leg PD holding hold_angle). Effectively, the
  gate now matches the user's mental model: "front pair is climbing -> back
  pair is fair game once IT also engages the step."

- **A4as — Detection diagnostic plot fields (debug A4ar's mystery).** A4ar
  added a manual fallback but the *real* question is "why does auto-detect
  fail when the wheel-velocity drop is obviously visible (28 -> 6 RPM)?".
  Either combined_score isn't crossing 1.0 (signal too weak after the LPF
  normalization), or it IS crossing but `detect_allowed` is false (a gate
  is blocking). Without per-leg visibility there's no way to tell remotely.
  Added five new Ozone-watchable fields in `DbgClimbPlot`:
    * `t_score[4]`        -- |residual-baseline|/t_thresh (settled-gated)
    * `w_score[4]`        -- wheel_drop/w_thresh
    * `combined_score[4]` -- t+w (>=1.0 = combined_hit fires)
    * `detect_allowed[4]` -- 1 if gate open (warmed + front_gate + !turning)
    * `detect_timer_s[4]` -- confirm-timer accumulation, peaks at detect_confirm_s
  Populated by `Climbing_Dynamics` DETECT case (zero outside DETECT --
  non-zero on an IDLE/PREP/CLIMBING/COMPLETE leg would indicate a logic
  bug). User insight that drove this: "感觉力矩残差不明显 速度残差更明显"
  -- the per-component scores let the user see WHICH residual is doing the
  work and whether the LPF normalization is the right ratio. If `w_score`
  alone routinely tops 1.5 while `t_score` stays at 0.2, we can drop the
  torque path for back legs entirely. Public getters added on
  `Climbing_Dynamics`: `getTorqueScore`, `getWheelScore`, `getDetectAllowed`,
  `getDetectTimer`. Chassis polls them every tick and stores into
  `dbg_climb_plot`. No behavior change -- diagnostics only.

- **A4ar — Manual BTN_X back-pair trigger (reliable fallback).** User HW
  showed clear wheel-velocity drops on BL (peaks 30 RPM, drops to 0/-10 of
  25-40 RPM magnitude) but auto-detect still didn't fire -- meaning one of
  the gates (front-COMPLETE, back_settle, detect_inhibit_) was blocking.
  Rather than keep debugging the auto path remotely, added a manual
  override: pressing BTN_X a SECOND time during ACTIVE (after the first
  press started PREP) force-triggers the BL/BR pair into CLIMBING,
  bypassing all DETECT gates. Only allowed when FL/FR are both COMPLETE
  (back can't climb before front geometrically). The user positions back
  wheels at the step, presses BTN_X, climb starts. New public method
  `Climbing_Dynamics::manualTriggerBackPair(bl_deg, br_deg)` that calls
  `beginClimbing` for legs 2 and 3 (no-op if not in DETECT). Diagnostic
  for auto-detect failure deferred: user to report phase[0/1],
  back_settle_remaining_s, detect_inhibited, wheel_rpm_drop[2/3] from
  Ozone when auto-trigger fails.

- **A4aq — User-directed: keep generous cap + harder CLIMBING Kp + COMBINED
  residual detection.** User feedback on A4ap: "climb_wheel_speed_ratio 5.0
  没问题，只要把 climbing kp 调硬就好了，BL BR 触发可以综合 leg 的扭矩
  wheel 的速度 两个残差 因为速度骤降很明显". Three changes:
  **(1) Revert A4ap cap rollback.** `climb_wheel_speed_ratio` 2->5,
  `CLIMB_ABSOLUTE_MAX_WHEEL_RPM` 25->40. The wheel-coupling safety issue
  is addressed by hardening the leg side, NOT by throttling the wheels --
  which the user needs generous to push the chassis through back climb.
  **(2) CLIMBING Kp 120 -> 200.** Matches DETECT stiffness. The leg now
  rigidly holds its trajectory regardless of wheel-coupling reaction
  torque. omega_ff (matched smoothstep derivative) keeps Kd from
  fighting commanded motion, so the high Kp doesn't make tracking stiff.
  This is the actual fix for the "leg gets bent forward, snaps back"
  safety bug.
  **(3) Combined sum-of-scores detection.** Replaces OR with weighted sum:
    - `t_score = torque_deviation / torque_threshold` (0..N)
    - `w_score = wheel_drop      / wheel_drop_threshold` (0..N)
    - Trigger when `t_score + w_score >= 1.0`
  Either signal alone at threshold fires (sum >= 1.0). Both at 0.6 fires
  (sum=1.2). Per-leg thresholds: front (t=4 Nm, w=25 RPM strict),
  back (t=2.5 Nm, w=12 RPM sensitive). The combined approach captures
  the user's HW observation: back contact has clear wheel decel (w
  contributes large) AND modest torque residual (t contributes some) ->
  reliable trigger via sum, even when neither alone clearly crosses.
  Also: Chassis wheel_blocked now = abs_stall ONLY (A4ao velocity drop
  removed from Chassis OR to avoid double-counting with the combined
  score in Climbing_Dynamics). `fb.wheel_drop` is now passed in the
  feedback for the combined score. wheel_blocked stays as a separate
  OR fallback for clean full-stall cases (front face-jam).

- **A4ap — EMERGENCY safety rollback (wheel coupling overwhelmed leg PD).**
  User HW: after A4aj raised the wheel cap (5x ratio + 40 RPM absolute),
  CLIMBING behavior changed dangerously -- "FL FR 触发后...变成瞬间到位，
  继续往前因为 wheel 的扭矩将 leg 往前掰，导致 leg 会去到前面 然后瞬间归位".
  Root cause: 40 RPM wheel cap gave the wheel motor enough authority that
  its reaction torque through the wheel-leg eccentric coupling overwhelmed
  the leg PD (Kp=80) during CLIMBING. The leg got deflected forward by
  wheel push past its trajectory target; when the push released or the
  wheel rolled out, the leg snapped back to target via Kp·err -- a violent
  "瞬间归位" that's a passenger-safety hazard.
  **Four rollbacks/hardenings:**
    1. `climb_wheel_speed_ratio` 5.0 -> 2.0 (A4aj revert).
    2. `CLIMB_ABSOLUTE_MAX_WHEEL_RPM` 40 -> 25 (A4aj revert, ~1/4 walking
       pace, no chassis surge feel).
    3. `WHEEL_DECEL_THRESHOLD` 10 -> 25 RPM (A4ao threshold raised; user
       push variation gives drops of 10-15 RPM which were false-triggering
       climb -- 25 RPM drop requires a genuinely big deceleration event).
    4. **CLIMBING Kp 80 -> 120**: leg PD stiffer so it resists the wheel
       coupling deflection in the first place. Smaller position error ->
       smaller (less violent) snap-back if wheel torque does briefly
       deflect the leg.
  Net: wheel motor authority limited (1+2), velocity-residual no longer
  spurious (3), leg holds trajectory firmer (4). Climbing might be slower
  (less wheel push) -- back-climb robustness may now need a manual BTN_X
  trigger backup (queued).

- **A4ao — Wheel-velocity RESIDUAL detection (mirror of torque residual).**
  User HW from BL wheel-RPM plot: wheel clearly decelerates at step
  contact but doesn't reach absolute-zero RPM -- the absolute stall check
  even at 15 RPM may not catch a wheel that drops from 30 -> 12 only
  briefly. User suggested "引入速度残差". **Implementation:** symmetric
  to leg torque residual:
    - Per-leg `wheel_rpm_baseline_[i]` updated with slow LPF (alpha=0.02,
      ~1.6 Hz tau ~100 ms).
    - `drop = wheel_rpm_baseline - |rpm|`. Positive when wheel slowed
      below its recent baseline.
    - `decel_spike = (drop > WHEEL_DECEL_THRESHOLD=10)` -> wheel decelerated
      >= 10 RPM from its smoothed baseline.
    - ORed with absolute stall in `raw_stall`. Either path triggers the
      stall timer / wheel_blocked output.
    - Reset baseline to current rpm on joystick release.
  Combined detection:
    - Front wheel hits face -> stalls to 0 -> absolute path triggers (5 RPM).
    - Back wheel scrapes edge -> decelerates 30 -> 12 -> velocity-residual
      path triggers (drop = 18 > 10).
    - Either way -> wheel_blocked -> Climbing_Dynamics DETECT fires.
  Plot: `dbg_climb_plot.wheel_rpm_baseline[4]`, `wheel_rpm_drop[4]` --
  watch alongside wheel RPM to see the residual catching events.

- **A4an — Split wheel-stall RPM threshold front/back.** User HW
  observation: "BL BR climb 的时候是会有减速现象，但不会堵转为 0，但是
  前轮 FL FR 是会堵住的". Different physics:
    - Front wheel hits step FACE directly -> HT motor brakes hard against
      the step -> wheel reaches near-zero RPM (true full stall).
    - Back wheel skim/scrapes the step EDGE during chassis-tilted
      approach -> decelerates from rolling (e.g. 30 RPM) down to 5-12 RPM
      but keeps slow-slipping (not fully stopped).
  Single stall threshold can't catch both. **Fix:** split to per-leg.
    - `WHEEL_STALL_RPM_FRONT = 5` RPM (strict, for the clean front stall)
    - `WHEEL_STALL_RPM_BACK = 15` RPM (relaxed, catches "decelerated past
      this point" even if still slow-slipping)
    - `WHEEL_ROLLING_RPM = 25` RPM (common, was_rolling latch threshold --
      higher than back stall threshold so there's no overlap)
  Both the front/back distinction AND the was_rolling latch (A4am) are
  needed: the latch handles startup false-trigger (spin-up never reaches
  ROLLING -> stall judgment OFF); the split threshold handles the
  rolling-vs-stall physics difference between front/back contact.

- **A4am — Wheel-stall STATE MACHINE (fix startup false-trigger).** User HW:
  "起步很慢并且有大扭矩 直接判断堵转 一动就直接 climb 了". Root cause:
  the simple "user pushing + low RPM + debounce" was fooled by heavy-load
  spin-up. From rest the wheel motor pulls high current to accelerate but
  takes 0.3-0.8 s to cross the 15 RPM threshold -- the raw stall is
  CONTINUOUSLY true through that window, so even the 0.2 s confirm fired
  falsely. **Fix:** per-leg "was_rolling" latch. The wheel must FIRST
  exceed `WHEEL_ROLLING_RPM` = 20 RPM (= genuinely spinning) before stall
  judgment is enabled. Then if the wheel drops back below
  `WHEEL_STALL_RPM` = 15 sustained 0.2 s -> stall. Reset on joystick
  release so each forward push attempt starts fresh.
    - Spin-up from rest: RPM rises 0->target, doesn't cross 20 yet ->
      was_rolling = false -> stall judgment OFF -> no false trigger.
    - Wheel rolled then hit step: RPM crossed 20 -> was_rolling = true,
      then dropped <15 (jam) -> timer accumulates -> trigger.

- **A4al — Split torque_res_threshold front/back.** User: "前后轮的触发
  阈值得单独调". Physical reason: front wheel hits the step face directly
  -> sharp clean torque spike, threshold can be higher. Back wheel often
  skim/scrapes the edge during approach (chassis tilted from A4af, weight
  in transition) -> weaker, noisier residual, needs lower threshold.
  **Implementation:**
    - `Climbing_Dynamics::Config::torque_res_threshold` (unchanged name,
      = FRONT, legacy Ozone watch still works). Default 4 Nm.
    - `Climbing_Dynamics::Config::torque_res_threshold_back` (new). Default
      2.5 Nm (lower).
    - DETECT picks `(i < 2) ? front : back` per leg.
    - `dbg_ctrl.torque_res_threshold` (front) + new
      `dbg_ctrl.torque_res_threshold_back` -- both Ozone-tunable live.
    - Plot: `dbg_climb_plot.torque_res_threshold_nm` (front) +
      `torque_res_threshold_back_nm` (back) for overlay.
  Tuning: use `dbg_climb_plot.residual_peak_nm[2],[3]` during back
  contact attempt -> set back threshold ~ 0.5*(peak - noise) + noise.

- **A4ak — Relax wheel-stall threshold (back detect didn't fire).** After
  A4aj fixed the wheel push (climb now possible), user reported back DETECT
  "根本没触发" -- never fires. The wheel_blocked condition was too strict:
  `user_pushing && |rpm| < 5 RPM` sustained 0.3 s. A wheel jammed against
  the step face often slips slowly at 5-12 RPM (friction creep), not full
  zero, so it never qualified. **Fix:**
    - RPM threshold 5 -> 15 (still well below normal driving, ~0.16 m/s)
    - Confirm time 0.30 -> 0.20 s (faster trigger, spin-up still ~0.1 s)

- **A4aj — Relaxed the wheel cap that was throttling back-climb push.**
  User HW (wheel current plot, dbg_wheel.cur_*): current was ~1-2 A elevated
  BEFORE BL/BR entered CLIMBING (user pushing fwd through DETECT), then
  DROPPED to near 0 the moment CLIMBING started. Diagnosis: A4xx's cap
  `phi_w * climb_wheel_speed_ratio(2) * 60/2pi` was ~15 RPM with phi_w=0.8,
  well below the user's push and well below what's needed to overcome the
  front-wheel brake-lock during back climb. The cap was DESIGNED to
  prevent wheel slip during front climb (where it worked fine), but for
  back climb the same cap suppresses the chassis-advance push that back
  actually requires.
  **Fix:**
    - `climb_wheel_speed_ratio` default 2.0 -> 5.0. With phi_w=0.8 this
      gives a phi_w-cap of ~38 RPM, comfortably above what the user push +
      A4ai auto-advance produces. Effectively the A4zz absolute ceiling
      becomes the operative limit.
    - `CLIMB_ABSOLUTE_MAX_WHEEL_RPM` 25 -> 40 RPM (=0.42 m/s wheel surface
      = ~1/3 walking pace). Still safe (no surge feel for the passenger),
      but enough to drive the back wheel through the step engagement.
  Together: during CLIMBING the user's joystick push + A4ai's auto-advance
  can deliver up to 40 RPM of forward wheel speed, with NO artificial
  throttling. Watch `dbg_climb_plot.climb_max_wheel_rpm` -- should now sit
  at 40, and `dbg_wheel.cur_*` should NOT crash to 0 when CLIMBING starts.

- **A4ai — Auto chassis-advance during CLIMBING (fix back can't climb).**
  User HW diagnosis: "目前触发是触发了 但是爬不动" -- BL/BR enter CLIMBING
  (phase=3), the trajectory runs, but the back wheels don't physically lift
  up the step. **Root cause:** the BACK climb requires the chassis to move
  FORWARD (geometric requirement of the wheel-pivot-around-step-edge model).
  The chassis advance requires the FRONT wheels (on the step surface) to
  roll forward. But HT wheel motors BRAKE when commanded 0 RPM -- if the
  user isn't pushing the joystick forward hard enough during the back
  climb, the front wheels stay locked, the chassis can't advance, and the
  back leg motor stalls (commanded to rotate but the chassis is pinned by
  the front wheels' brake). The trajectory β keeps integrating but the leg
  can't follow because the world won't move. Front climb didn't have this
  because back wheels were on flat ground and could skid; front wheels on
  the step face brake-lock the chassis.
  **Fix:** add an automatic forward wheel drive during any CLIMBING phase,
  at the KINEMATIC chassis-advance rate `cos(beta) * phi_w * scale` (wheel
  RPM equivalent). phi_w is smoothstep-ramped (A4ww), so the drive ramps
  in smoothly -- no jerk like the old A4ll-removed `climb_base_rpm` (which
  was a crude fixed boost). scale (default 1.5) adds grip margin so the
  climbing wheel is also pushed against the step edge to help it climb up.
  Added to `vx` before inverseKinematics; the A4xx cap still applies.
  Now the chassis ADVANCES on its own during climbing -- user push is
  optional (still works, adds on top). Tunable: `dbg_ctrl.climb_advance_scale`,
  raise 1.5->2.5 if back climb still sluggish, lower if chassis surges.
  Plot: `dbg_climb_plot.climb_advance_rpm` shows the active forward drive.

- **A4ah — Debounce wheel-stall (fix spin-up false-trigger).** User caught
  the bug: at the START of a forward push the wheel motor hasn't spun up
  yet (RPM still ~0), so the raw `user_pushing && |rpm|<5` condition is TRUE
  for the first few ticks -> A4ag would false-trigger climb the instant the
  joystick moves. **Fix:** per-leg `wheel_stall_timer_` in Chassis
  accumulates while the raw stall holds and resets when the wheel rolls;
  `wheel_blocked` only fires after the timer exceeds `WHEEL_STALL_CONFIRM_S`
  = 0.30 s. A genuine step-jam holds the wheel at ~0 indefinitely (timer
  passes 0.3 s -> blocked); a spin-up transient clears within ~0.1 s as the
  wheel starts rolling (timer resets -> never blocked). Stall detection is
  thus ~0.3 s slower but immune to the push-start transient.

- **A4ag — Wheel-stall as a second step-contact detection signal.** User HW:
  "FL FR 上了，BL BR 卡住蹭台阶边缘 上不去" -- back wheels reach the step
  but scrape the edge without climbing. The torque-residual path can fail
  for the back wheel: scraping induces leg vibration that fails the
  `detect_settle_omega` gate, and/or the residual is too weak. **Fix:** a
  second, independent contact signal -- `LegClimbFeedback::wheel_blocked`:
  the user is commanding forward (left-stick past deadzone) but the wheel
  RPM is ~0 (< 5 RPM) -> the wheel is jammed against the step face. This is
  an unambiguous "wheel at step" indicator that doesn't depend on leg
  torque OR the settle gate. DETECT now triggers on
  `(settled && residual>threshold) || wheel_blocked`, sustained for
  detect_confirm_s, while detection is allowed (front-gate + not-turning).
  Computed in Chassis (has both the joystick command and wheel RPM),
  passed per-leg in the feedback. Plot: `dbg_climb_plot.wheel_blocked[4]`.
  **DIAGNOSIS STILL NEEDED:** if BL/BR scrape, the user must report whether
  phase[2],[3] are stuck at 2 (DETECT -- detection not firing, A4ag should
  now help) or reach 3 (CLIMBING -- triggering but can't physically lift,
  which would point to load/torque/trajectory, a different fix). Also note:
  during back CLIMBING the user must KEEP pushing forward so the front
  wheels roll on the step and the chassis advances -- otherwise the back is
  geometrically locked and can't pivot up.

- **A4af — Direct front-leg drop for CoM-forward (replaces weak pitch).**
  User HW report: back wheels can't climb because "重心全压在后轮", and
  "完全没看到 FL FR complete 之后的 BL BR 伸长，前倾". Diagnosis:
    - A4ae's pitch tilt used the body-PID dtheta (attenuated by lev_scale
      0.25 * BODY_PID_SCALE 0.7 = 0.175) and only produced ~1deg -- not
      visible, not effective.
    - The user expected BL/BR to EXTEND, but back-leg extension at 165deg
      has near-zero geometric authority (sin=0.26 -> 0.32 mm/deg) AND
      approaches the seam. It physically can't produce meaningful tilt.
  **Effective mechanism = lower the FRONT legs.** At their end-climb angle
  ~62deg, sin=0.88 -> 1.08 mm/deg, 3x the authority of the back at 165deg.
  Lowering front legs drops the chassis front -> nose-down -> CoM forward
  -> back wheels unloaded. **Fix:** new `dbg_ctrl.climb_front_drop_deg`
  (default 15deg). In the climbing direct branch, when a FRONT leg is in
  COMPLETE and the back legs haven't both COMPLETE yet, subtract
  climb_front_drop_deg from its target angle (re-clamped to >= prep_margin).
  Direct, strong, visible: 15deg front lowering (62->47) gives ~19mm
  chassis drop -> ~3.6deg nose-down. Released once all four legs COMPLETE.
  Front wheels stay on the step (they're resting on top); only the chassis
  attitude changes. Tunable: raise for more CoM shift (watch for tip-
  forward over the step edge), lower for less.
  NOTE: the A4ae body-PID pitch dtheta (COMPLETE-only, +-15 clamp) still
  exists and stacks a small additional tilt, but climb_front_drop_deg is
  now the primary, deterministic CoM-shift knob.

- **A4ae — Coupled-pair detection trigger + stronger post-front pitch.**
  User HW report: "实际 fb deg 为 +-1deg 基本没有变化"(pitch tilt too weak)
  and "FL FR 残差检测...有时一个触发一个不触发，有时都不触发"(detection
  unreliable). Two fixes:
  **(1) Coupled-pair trigger (detection robustness).** The two front wheels
  (or two back wheels) physically contact the same step edge together, but
  per-leg friction / approach-angle differences make one leg's residual
  cross threshold well before the other -- and sometimes the laggard never
  crosses. New `beginClimbing(idx, motor_deg)` helper; when EITHER leg of a
  pair confirms contact, BOTH legs of that pair (front {0,1} or back {2,3})
  transition DETECT->CLIMBING, each seeding beta from its own motor angle.
  Fixes "one triggers, one doesn't"; also helps "neither" since only ONE
  leg now needs to cross threshold.
  **(2) Post-front pitch authority.** The +-1deg the user saw was the +-5deg
  dtheta clamp at extended leg angles. Two changes:
    - Pitch dtheta now applies ONLY in COMPLETE phase (was CLIMBING+COMPLETE).
      During CLIMBING the trajectory drives theta 165->62; a +10deg nose-up
      dtheta FOUGHT that motion. Removing it from CLIMBING = clean pivot.
    - dtheta clamp +-5 -> +-15 deg. Safe now because it only acts in
      COMPLETE where front legs are at ~62deg (sin=0.88, good authority,
      far from seam; new_theta [15,165] clamp still catches it). Post-front
      nose-down now reaches ~3deg (15mm front-leg lowering) instead of ~1deg.
  NOTE: the PREP nose-up (+10deg) is now effectively unused (PREP gated, and
  it fought the climb anyway). The useful pitch is the post-front nose-down
  in COMPLETE. If stronger CoM shift still needed, raise the clamp further
  or lower prep/end-climb angles.
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

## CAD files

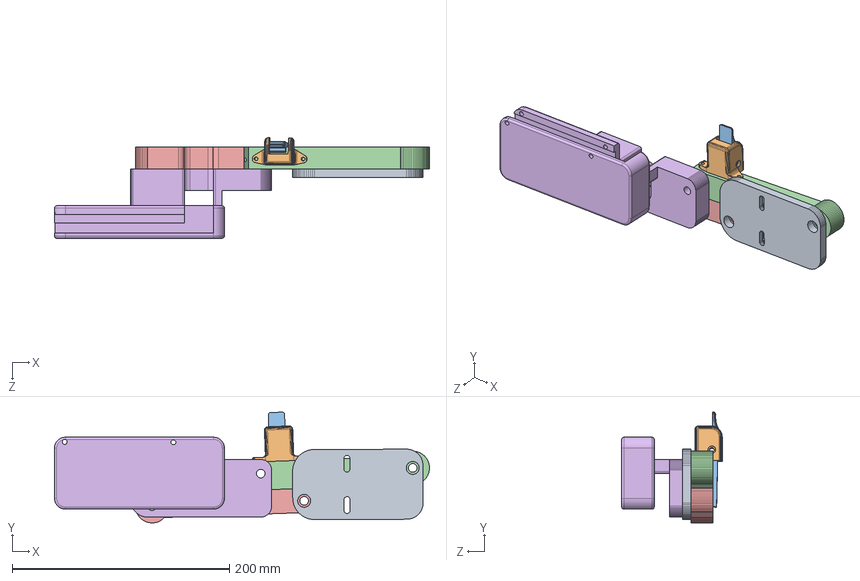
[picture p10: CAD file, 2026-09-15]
hardware/interface-cad/Assem3.SLDASM
345.2 x 102.0 x 92.6 mm
Part2_base
Part3_y
Part4_y
Part6_y
Part9_y
Part7_y

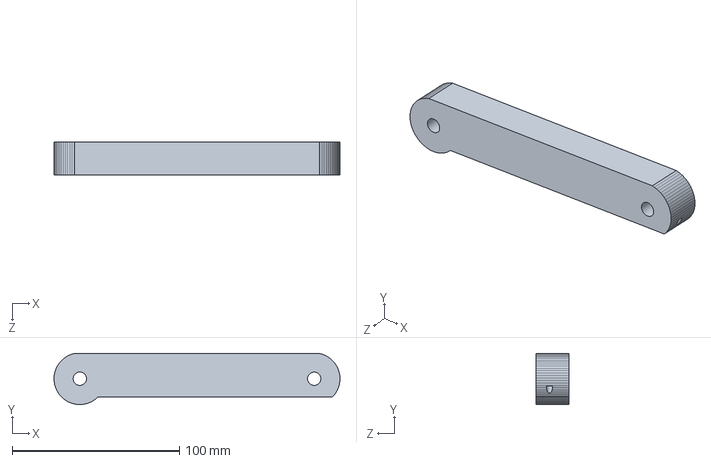
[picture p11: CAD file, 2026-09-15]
hardware/interface-cad/Part4_y.SLDPRT
170.8 x 30.5 x 20.0 mm

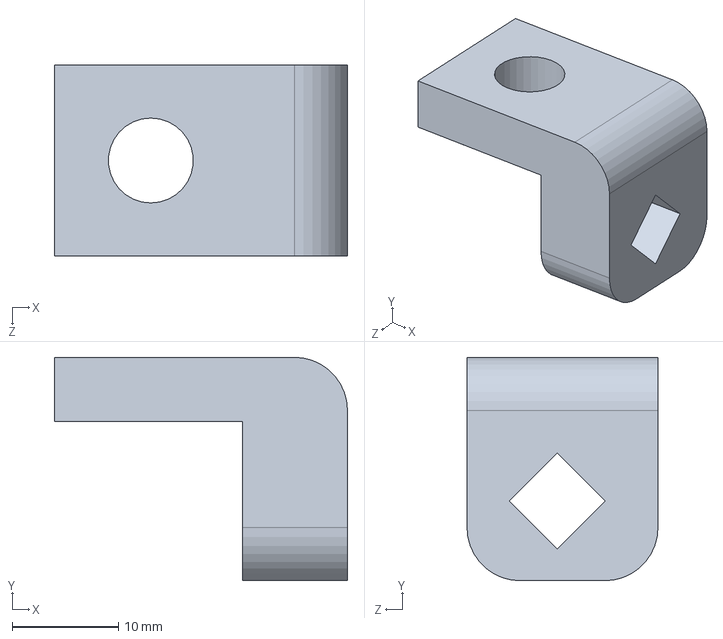
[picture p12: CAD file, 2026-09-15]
hardware/interface-cad/Part10.SLDPRT
27.6 x 21.1 x 18.0 mm

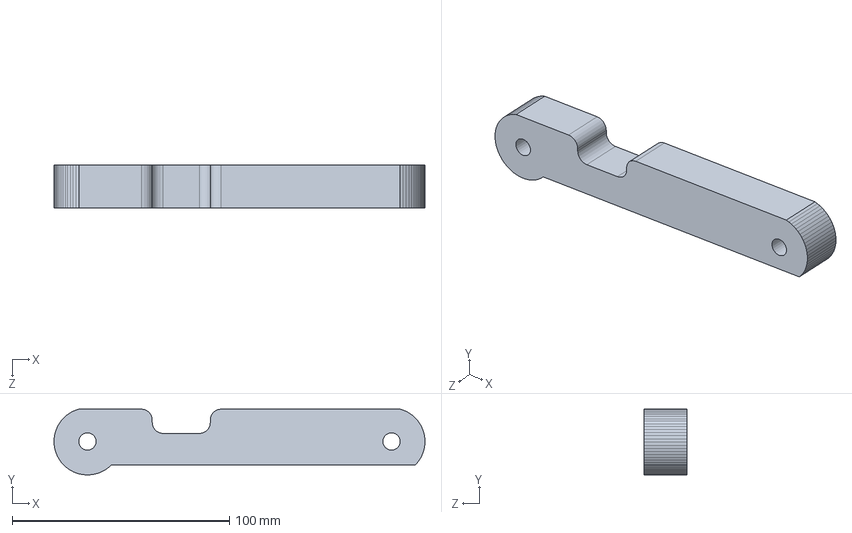
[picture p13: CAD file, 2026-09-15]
hardware/interface-cad/Part3_y.SLDPRT
170.8 x 30.3 x 20.0 mm

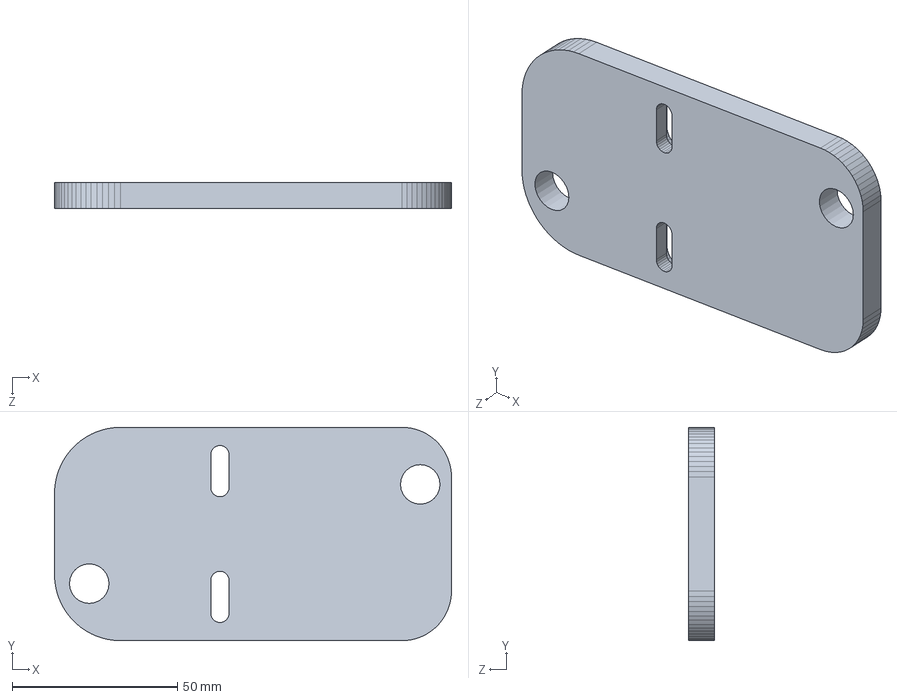
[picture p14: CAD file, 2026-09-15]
hardware/interface-cad/Part7_y.SLDPRT
120.0 x 64.5 x 8.00 mm

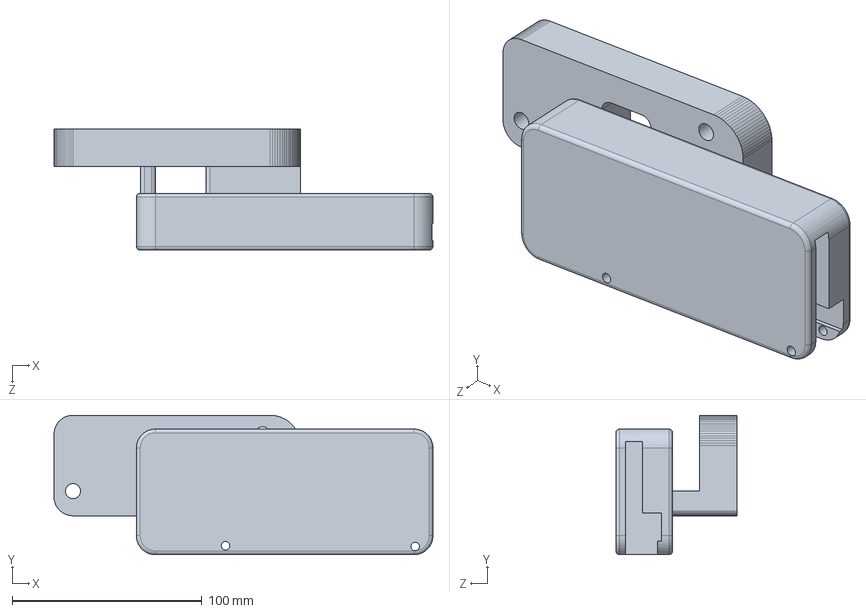
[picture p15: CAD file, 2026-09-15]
hardware/interface-cad/Part2_base.SLDPRT
199.9 x 73.5 x 64.0 mm

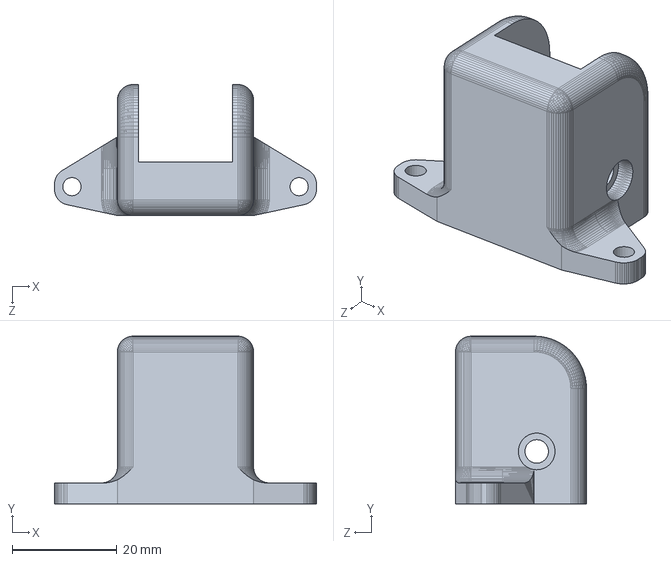
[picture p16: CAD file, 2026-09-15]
hardware/interface-cad/Part9_y.SLDPRT
50.0 x 32.0 x 25.0 mm

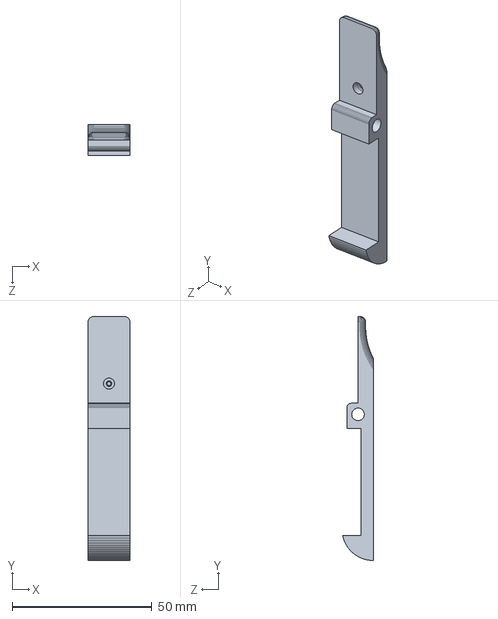
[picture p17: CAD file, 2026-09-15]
hardware/interface-cad/Part6_y.SLDPRT
15.0 x 87.2 x 11.0 mm

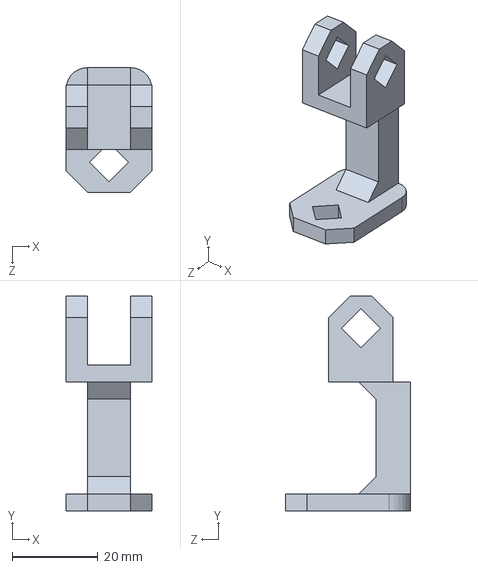
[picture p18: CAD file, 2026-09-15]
hardware/interface-cad/Part11.SLDPRT
20.0 x 50.0 x 29.0 mm

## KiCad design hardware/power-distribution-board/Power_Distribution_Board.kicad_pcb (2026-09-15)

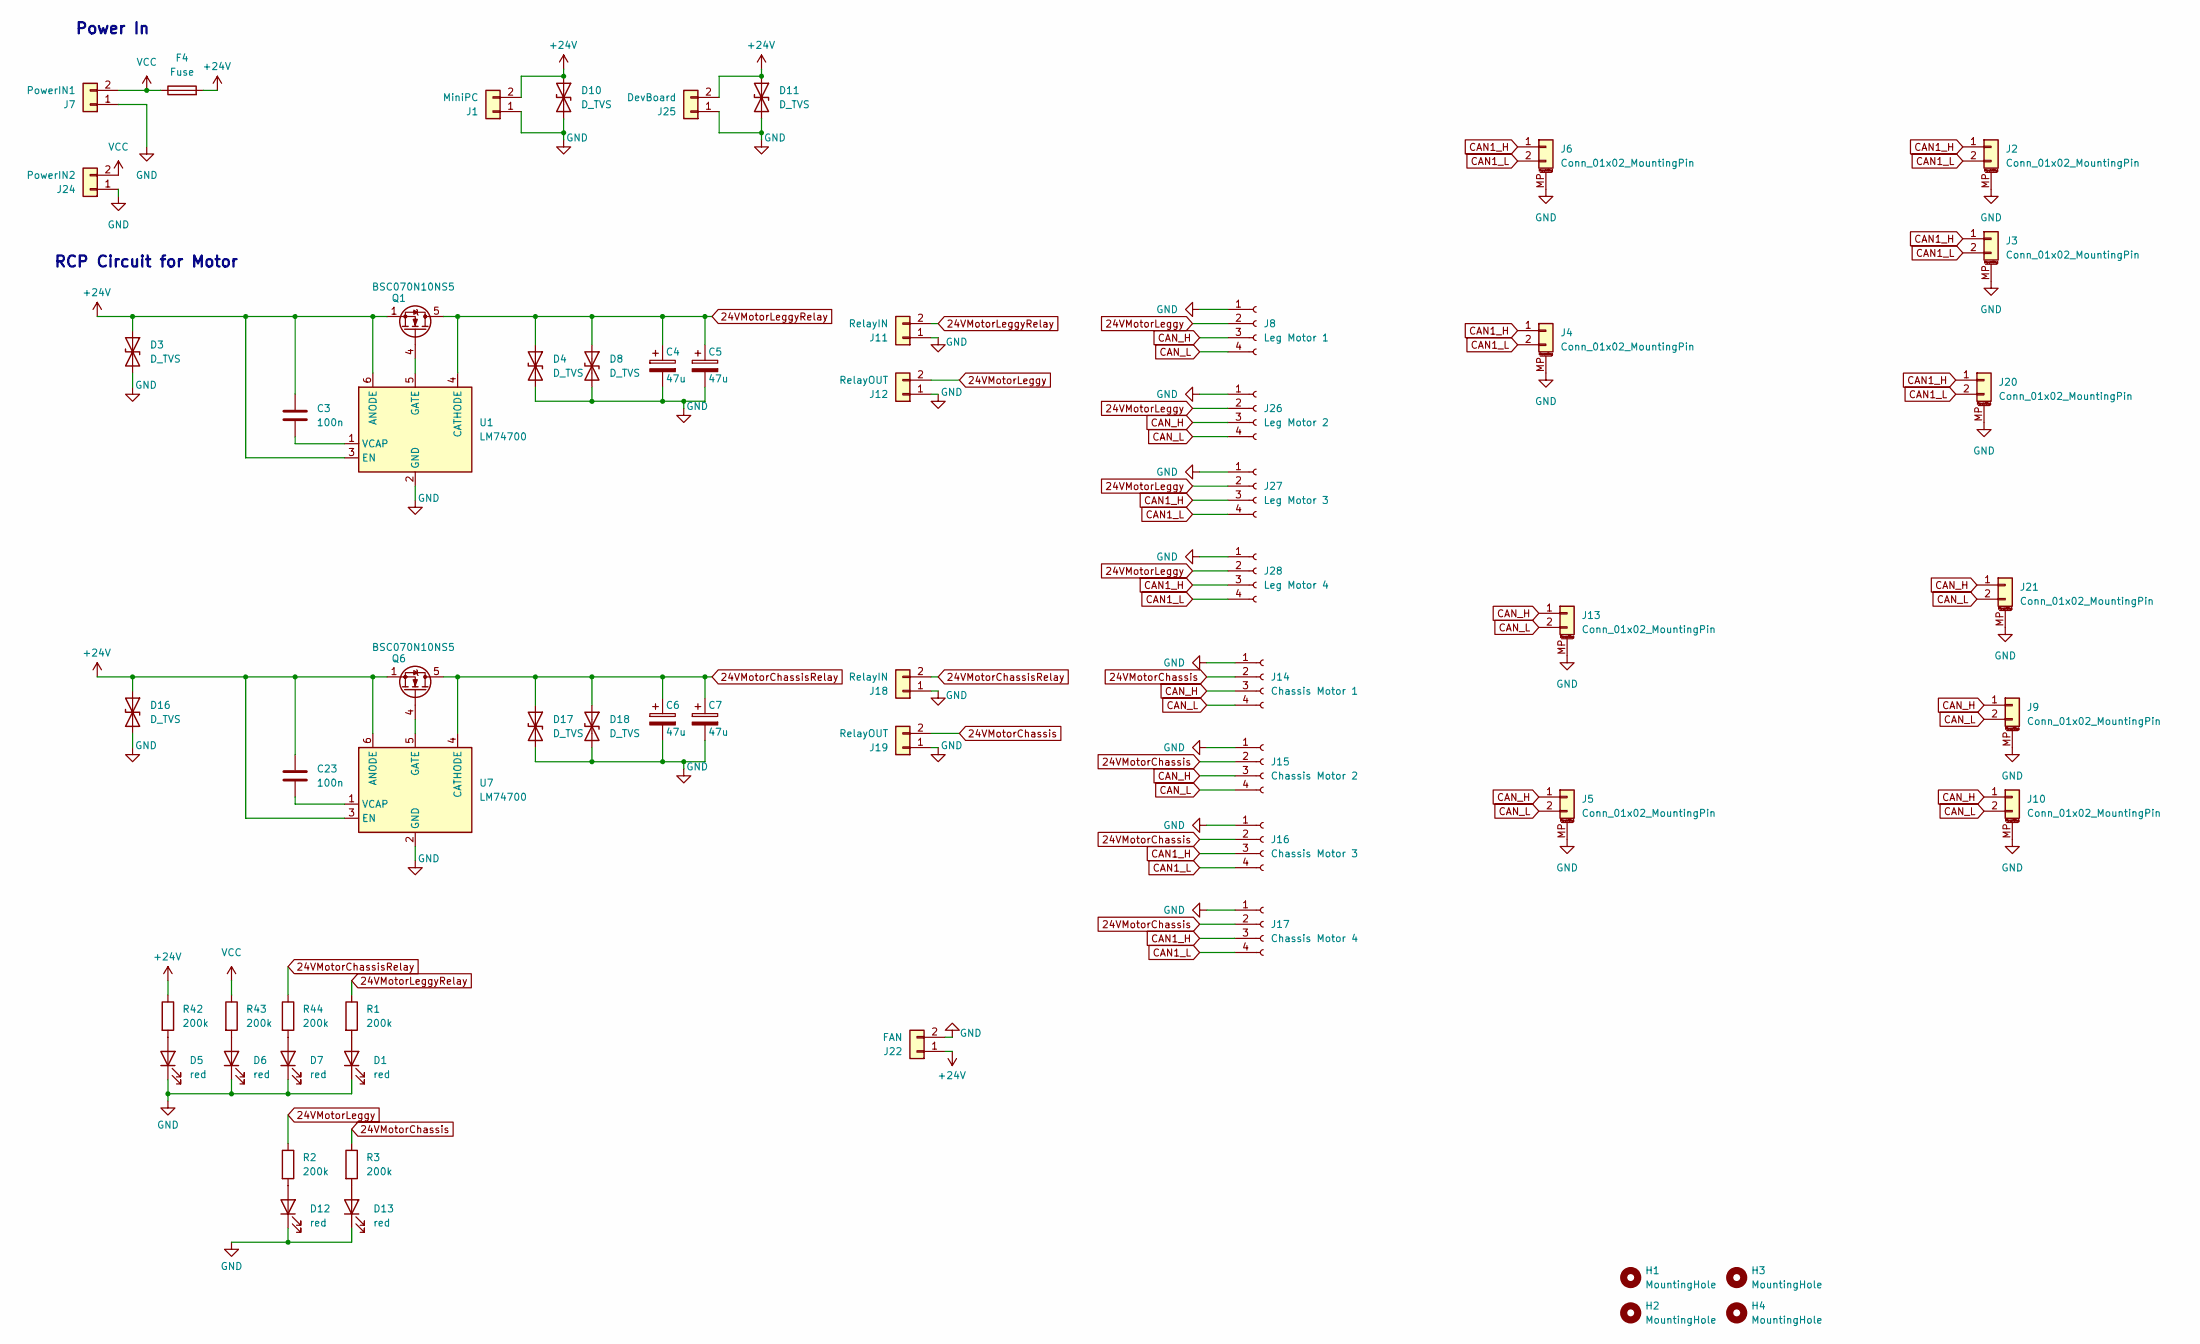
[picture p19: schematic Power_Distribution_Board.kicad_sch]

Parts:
C3, C23: 100n; C_0603_1608Metric; LCSC C14663
C4, C5, C6, C7: 47u; CP_Radial_D16.0mm_P7.50mm
D1, D5, D6, D7, D12, D13: red; LED_0603_1608Metric; LCSC C84256
D3, D4, D8, D10, D11, D16, D17, D18: D_TVS; D_SMC
F4: Fuse; FuseHolderSMD9.7x5mm
H1, H2, H3, H4: MountingHole; MountingHole_3.2mm_M3_Pad_Via
J1: MiniPC; AMASS_XT30U-M_1x02_P5.0mm_Vertical
J2, J3, J4, J5, J6, J9, J10, J13, J20, J21: Conn_01x02_MountingPin; JST_GH_BM02B-GHS-TBT_1x02-1MP_P1.25mm_Vertical
J7: PowerIN1; AMASS_XT60-F_1x02_P7.20mm_Vertical
J8: Leg Motor 1; AMASS_XT30_2+2_1x02_P5.0mm_Vertical
J11, J18: RelayIN; AMASS_XT60-F_1x02_P7.20mm_Vertical
J12, J19: RelayOUT; AMASS_XT60-F_1x02_P7.20mm_Vertical
J14: Chassis Motor 1; AMASS_XT30_2+2_1x02_P5.0mm_Vertical
J15: Chassis Motor 2; AMASS_XT30_2+2_1x02_P5.0mm_Vertical
J16: Chassis Motor 3; AMASS_XT30_2+2_1x02_P5.0mm_Vertical
J17: Chassis Motor 4; AMASS_XT30_2+2_1x02_P5.0mm_Vertical
J22: FAN; JST_XH_B2B-XH-A_1x02_P2.50mm_Vertical
J24: PowerIN2; AMASS_XT60-F_1x02_P7.20mm_Vertical
J25: DevBoard; AMASS_XT30U-M_1x02_P5.0mm_Vertical
J26: Leg Motor 2; AMASS_XT30_2+2_1x02_P5.0mm_Vertical
J27: Leg Motor 3; AMASS_XT30_2+2_1x02_P5.0mm_Vertical
J28: Leg Motor 4; AMASS_XT30_2+2_1x02_P5.0mm_Vertical
Q1, Q6: BSC070N10NS5; TDSON-8-1
R1, R2, R3, R42, R43, R44: 200k; R_0603_1608Metric; LCSC C23186
U1, U7: LM74700; SOT-23-6

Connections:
24VMotorChassis: J14.2, J15.2, J16.2, J17.2, J19.2, R3.1
24VMotorChassisRelay: C6.1, C7.1, D17.1 (A1), D18.1 (A1), J18.2, Q6.5 (D), R44.1, U7.4 (CATHODE)
24VMotorLeggy: J8.2, J12.2, J26.2, J27.2, J28.2, R2.1
24VMotorLeggyRelay: C4.1, C5.1, D4.1 (A1), D8.1 (A1), J11.2, Q1.5 (D), R1.1, U1.4 (CATHODE)
+24V: C3.1, C23.1, D3.1 (A1), D10.1 (A1), D11.1 (A1), D16.1 (A1), F4.2, J1.2, J22.1, J25.2, Q1.1 (S), Q1.2 (S), Q1.3 (S), Q6.1 (S), Q6.2 (S), Q6.3 (S), R42.1, U1.3 (EN), U1.6 (ANODE), U7.3 (EN), U7.6 (ANODE)
CAN1_H: J2.1, J3.1, J4.1, J6.1, J16.3, J17.3, J20.1, J27.3, J28.3
CAN1_L: J2.2, J3.2, J4.2, J6.2, J16.4, J17.4, J20.2, J27.4, J28.4
CAN_H: J5.1, J8.3, J9.1, J10.1, J13.1, J14.3, J15.3, J21.1, J26.3
CAN_L: J5.2, J8.4, J9.2, J10.2, J13.2, J14.4, J15.4, J21.2, J26.4
GND: C4.2, C5.2, C6.2, C7.2, D1.1 (K), D3.2 (A2), D4.2 (A2), D5.1 (K), D6.1 (K), D7.1 (K), D8.2 (A2), D10.2 (A2), D11.2 (A2), D12.1 (K), D13.1 (K), D16.2 (A2), D17.2 (A2), D18.2 (A2), J1.1, J2.MP (MountPin), J3.MP (MountPin), J4.MP (MountPin), J5.MP (MountPin), J6.MP (MountPin), J7.1, J8.1, J9.MP (MountPin), J10.MP (MountPin), J11.1, J12.1, J13.MP (MountPin), J14.1, J15.1, J16.1, J17.1, J18.1, J19.1, J20.MP (MountPin), J21.MP (MountPin), J22.2, J24.1, J25.1, J26.1, J27.1, J28.1, U1.2 (GND), U7.2 (GND)
unnamed: D1.2 (A), R1.2
unnamed: D5.2 (A), R42.2
unnamed: D6.2 (A), R43.2
unnamed: D7.2 (A), R44.2
unnamed: D12.2 (A), R2.2
unnamed: D13.2 (A), R3.2
unnamed: Q1.4 (G), U1.5 (GATE)
unnamed: Q6.4 (G), U7.5 (GATE)
unnamed: C3.2, U1.1 (VCAP)
unnamed: C23.2, U7.1 (VCAP)
VCC: F4.1, J7.2, J24.2, R43.1

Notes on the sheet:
RCP Circuit for Motor
Power In

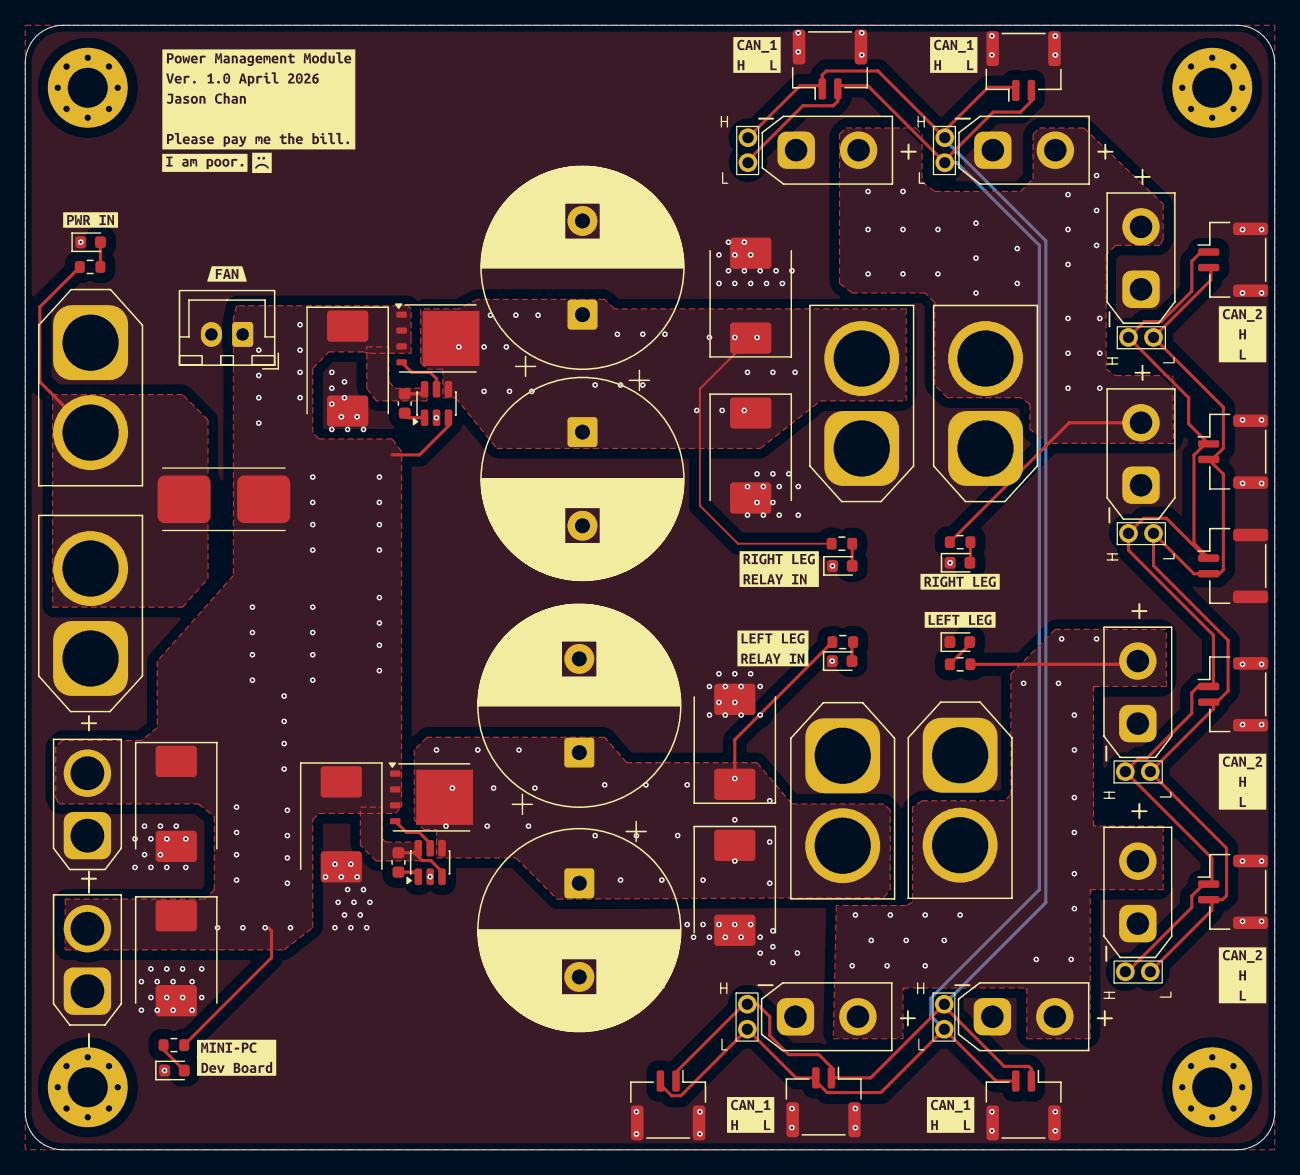
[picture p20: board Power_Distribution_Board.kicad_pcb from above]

Board: 4 copper layers, 100.0 x 90.0 mm, 79 parts (0 on the bottom side), 21 nets.

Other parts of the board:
kibuzzard-69E79C0F: G***; kibuzzard-69E79C0F
kibuzzard-69E79C2E: G***; kibuzzard-69E79C2E
kibuzzard-69E79C27: G***; kibuzzard-69E79C27
kibuzzard-69E797B3: G***; kibuzzard-69E797B3
kibuzzard-69E797CC: G***; kibuzzard-69E797CC
kibuzzard-69E798A9, kibuzzard-69E798A9#2, kibuzzard-69E798A9#3: G***; kibuzzard-69E798A9
kibuzzard-69E7980C: G***; kibuzzard-69E7980C
kibuzzard-69E7988C, kibuzzard-69E7988C#2, kibuzzard-69E7988C#3, kibuzzard-69E7988C#4: G***; kibuzzard-69E7988C
kibuzzard-69E79826: G***; kibuzzard-69E79826
kibuzzard-69E79832: G***; kibuzzard-69E79832
kibuzzard-69E79866: G***; kibuzzard-69E79866
kibuzzard-69E87184: G***; kibuzzard-69E87184

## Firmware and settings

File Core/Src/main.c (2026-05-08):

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
/* Includes ------------------------------------------------------------------*/
#include "main.h"
#include "cordic.h"
#include "dma.h"
#include "fdcan.h"
#include "spi.h"
#include "tim.h"
#include "usart.h"
#include "gpio.h"


void SystemClock_Config(void);
/**
  * @brief  The application entry point.
  * @retval int
  */
int main(void)
{
  /* MCU Configuration--------------------------------------------------------*/

  /* Reset of all peripherals, Initializes the Flash interface and the Systick. */
  HAL_Init();

  /* Configure the system clock */
  SystemClock_Config();

  /* USER CODE BEGIN SysInit */
    /* Write Flash OB (G4 series) */
  FLASH_OBProgramInitTypeDef pOBInit;
  HAL_FLASHEx_OBGetConfig(&pOBInit);
  if (!((pOBInit.USERConfig & FLASH_OPTR_nSWBOOT0_Msk) == OB_BOOT0_FROM_OB &&
        (pOBInit.USERConfig & FLASH_OPTR_nBOOT0_Msk) == OB_nBOOT0_SET &&
        (pOBInit.USERConfig & FLASH_OPTR_NRST_MODE_Msk) == OB_NRST_MODE_GPIO &&
        (pOBInit.USERConfig & FLASH_OPTR_BOR_LEV_Msk) == OB_BOR_LEVEL_4 &&
        (pOBInit.USERConfig & FLASH_OPTR_nRST_STOP_Msk) == OB_STOP_RST &&
        (pOBInit.USERConfig & FLASH_OPTR_nRST_STDBY_Msk) == OB_STANDBY_RST &&
        (pOBInit.USERConfig & FLASH_OPTR_nRST_SHDW_Msk) == OB_SHUTDOWN_RST
  )) {
      __disable_irq();
      HAL_FLASH_Unlock();
      HAL_FLASH_OB_Unlock();

      pOBInit.OptionType = OPTIONBYTE_USER;
      pOBInit.USERType = 0;
      pOBInit.USERConfig = 0;

      pOBInit.USERType |= OB_USER_nSWBOOT0;
      pOBInit.USERConfig |= OB_BOOT0_FROM_OB;
      pOBInit.USERType |= OB_USER_nBOOT0;
      pOBInit.USERConfig |= OB_nBOOT0_SET;
      pOBInit.USERType |= OB_USER_NRST_MODE;
      pOBInit.USERConfig |= OB_NRST_MODE_GPIO;
      pOBInit.USERType |= OB_USER_BOR_LEV;
      pOBInit.USERConfig |= OB_BOR_LEVEL_4;
      pOBInit.USERType |= OB_USER_nRST_STOP;
      pOBInit.USERConfig |= OB_STOP_RST;
      pOBInit.USERType |= OB_USER_nRST_STDBY;
      pOBInit.USERConfig |= OB_STANDBY_RST;
      pOBInit.USERType |= OB_USER_nRST_SHDW;
      pOBInit.USERConfig |= OB_SHUTDOWN_RST;
      pOBInit.USERType |= OB_USER_IRHEN;
      pOBInit.USERConfig |= OB_IRH_ENABLE;
      HAL_FLASHEx_OBProgram(&pOBInit);
      HAL_FLASH_OB_Launch();
      HAL_FLASH_OB_Lock();
      HAL_FLASH_Lock();
      __enable_irq();

  }

  /* USER CODE END SysInit */

  /* Initialize all configured peripherals */
  MX_GPIO_Init();
  MX_DMA_Init();
  MX_FDCAN1_Init();
  MX_FDCAN2_Init();
  MX_FDCAN3_Init();
  MX_UART4_Init();
  MX_UART5_Init();
  MX_USART2_UART_Init();
  MX_USART3_UART_Init();
  MX_SPI1_Init();
  MX_CORDIC_Init();
  MX_TIM16_Init();
  MX_USART1_UART_Init();
  MX_TIM20_Init();
  /* USER CODE BEGIN 2 */
  extern void startRTOS(void);
  startRTOS();   

  /* USER CODE END 2 */

  /* Infinite loop */
  /* USER CODE BEGIN WHILE */
  while (1)
  {
    /* USER CODE END WHILE */

    /* USER CODE BEGIN 3 */
  }
  /* USER CODE END 3 */
}

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
/**
  * @brief  Period elapsed callback in non blocking mode
  * @note   This function is called  when TIM7 interrupt took place, inside
  * HAL_TIM_IRQHandler(). It makes a direct call to HAL_IncTick() to increment
  * a global variable "uwTick" used as application time base.
  * @param  htim : TIM handle
  * @retval None
  */
void HAL_TIM_PeriodElapsedCallback(TIM_HandleTypeDef *htim)
{
  if (htim->Instance == TIM7) {
    HAL_IncTick();
  }
}

/**
  * @brief  This function is executed in case of error occurrence.
  * @retval None
  */
void Error_Handler(void)
{
  /* USER CODE BEGIN Error_Handler_Debug */
  /* User can add his own implementation to report the HAL error return state */
  __disable_irq();
  while (1)
  {
  }
  /* USER CODE END Error_Handler_Debug */
}

#ifdef  USE_FULL_ASSERT
/**
  * @brief  Reports the name of the source file and the source line number
  *         where the assert_param error has occurred.
  * @param  file: pointer to the source file name
  * @param  line: assert_param error line source number
  * @retval None
  */
void assert_failed(uint8_t *file, uint32_t line)
{
  /* USER CODE BEGIN 6 */
  /* User can add his own implementation to report the file name and line number,
     ex: printf("Wrong parameters value: file %s on line %d\r\n", file, line) */
  /* USER CODE END 6 */
}
#endif /* USE_FULL_ASSERT */

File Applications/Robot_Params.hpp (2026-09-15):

/**
 * @file    Robot_Params.hpp
 * @brief   Mechanical constants and tuning parameters: CircLeg geometry, chassis
 *          dimensions, masses, IMU mounting, control gains and safety limits.
 *
 * Circle_Leg_V2 - REACHABLE (QuadCirc) full-size prototype firmware.
 *
 * @author  LIU Hualin
 */

#pragma once

#ifndef PI
#define PI 3.1415926535f
#endif

#ifndef TWO_PI
#define TWO_PI (2.0f * PI)
#endif

#define LEG_MOTOR_NUM 4
#define WHEEL_MOTOR_NUM 4

/*
                                    WHEEL_TRACK BACK
                HT8115 ID4 ------------------------- HT8115 ID2
        DM10010 ID0x04 (BR) ------------------------- DM10010 ID0x02 (BL)
                            |                     |
                            |                     |
                            |                     |
                            |                     |
                            |                     |
                            |                     |
        HT8115 ID3 ------------------------------------ HT8115 ID1
DM10010 ID0x03 (FR) ------------------------------------ DM10010 ID0x01 (FL)
                                WHEEL_TRACK FRONT


*/

// ==========================================
//        Leg Motor Configuration
// ==========================================

// Active leg motor selection. Exactly one must be 1.
// In this build: legs are DM J10010L_2EC on CAN1, wheels are HT8115 on CAN2.
#define USE_DM_LEG_MOTOR 1    // 1: use DM J10010L_2EC as leg motor;
#define USE_HT_LEG_MOTOR 0    // 1: use HT8115 as leg motor;
#define USE_6020_LEG_MOTOR 0  // 1: use DJI GM6020 as leg motor;

#if USE_6020_LEG_MOTOR
#define GM6020_ID1_OFFSET -2.050f
#define GM6020_ID2_OFFSET -0.070f
#define GM6020_ID3_OFFSET -0.040f
#define GM6020_ID4_OFFSET 1.000f

#elif USE_HT_LEG_MOTOR
#define HT8115_ID1_OFFSET 0.0f
#define HT8115_ID2_OFFSET 0.0f
#define HT8115_ID3_OFFSET 0.0f
#define HT8115_ID4_OFFSET 0.0f

#elif USE_DM_LEG_MOTOR
// ------------------------------------------------------------
// DM J10010L_2EC absolute-position offsets (radians).
//
// Definition:
//   The value is the RAW encoder reading getPositionFeedback() (rad)
//   when the leg is at its mechanical LOWEST / fully-EXTENDED pose
//   (i.e. when our logical leg_pos == 0°, see INITIAL_LEG_ANGLE).
//
// Used by Wheel_Leg as:
//   leg_pos[deg] = rad2deg( normalizeAngle( fb_rad - leg_offset ) )
//
// Calibration procedure (one-time, no need to SetZero on each power-up):
//   1. Power on, keep DM motors disabled.
//   2. Manually push each leg DOWN to its mechanical hard stop (lowest).
//   3. Read getPositionFeedback() (rad) for that motor.
//   4. Paste the value into the corresponding macro below.
//
// Unit helper: define in degrees if more convenient, then convert.
//   #define DM_LEG_ID1_OFFSET (deg2radf(123.4f))
// ------------------------------------------------------------

// Pre-measured raw encoder values at lowest pose (rad).
// All four motors had setZeroPosition() called at the mechanical lowest pose
// (DM flash already stores that as zero), so getPositionFeedback() ≈ 0 there.
#define DM_LEG_ID1_OFFSET 0.0f  // FL
#define DM_LEG_ID2_OFFSET 0.0f  // BL
#define DM_LEG_ID3_OFFSET 0.0f  // FR
#define DM_LEG_ID4_OFFSET 0.0f  // BR
#endif
// ==========================================
//        Mechanical Parameters
// ==========================================

// Wheel-Leg Geometry
#define ECCENTRIC_OFFSET_r 90.0f
#define WHEEL_RADIUS_R 177.5f

// Chassis Dimensions
#define WHEEL_TRACK_FRONT 620.0f  // Distance between Front Left and Front Right
#define WHEEL_TRACK_BACK 480.0f   // Distance between Back Left and Back Right
#define WHEEL_BASE 385.0f         // Distance between Front Axle and Back Axle

// IMU Mounting Position (Relative to Chassis Geometric Center)
// Positive X: Forward, Positive Y: Left, Positive Z: Up
#define IMU_MOUNT_X 0.0f
#define IMU_MOUNT_Y 0.0f
#define IMU_MOUNT_Z 0.0f

// IMU Mounting Orientation (Relative to Chassis Frame)
// Unit: Degrees
// Current physical mount: IMU is rotated +90° CCW about chassis Z (top-down view),
// otherwise level (no roll/pitch offset).
#define IMU_MOUNT_ROLL_DEG 0.0f
#define IMU_MOUNT_PITCH_DEG 0.0f
#define IMU_MOUNT_YAW_DEG 90.0f

// IMU level-trim offsets (degrees, in chassis frame AFTER mount transform).
// Measured while the chassis sits perfectly level on a flat surface; we subtract
// these from the transformed pitch/roll so "level" reads (0, 0).
//   Reading on flat ground (May 2026): pitch = -4°, roll = +1.3°
#define IMU_PITCH_OFFSET_DEG -4.0f
#define IMU_ROLL_OFFSET_DEG 1.3f
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

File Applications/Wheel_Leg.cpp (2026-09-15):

/**
 * @file    Wheel_Leg.cpp
 * @brief   One CircLeg corner (wheel motor + eccentric leg motor): height <-> angle
 *          conversion, MIT leg command pipeline, wheel velocity loop and wheel-leg
 *          decoupling compensation.
 *
 * Circle_Leg_V2 - REACHABLE (QuadCirc) full-size prototype firmware.
 *
 * @author  LIU Hualin
 */

#include "Wheel_Leg.hpp"

#include <cmath>

namespace Applications
{

Wheel_Leg::Wheel_Leg(Motors::HT8115 *wheel_motor_,
                     Motors::J10010L_2EC *leg_motor_,
                     MIT_Params mit_pid_,
                     float leg_offset_,
                     int bending_direction,
                     float wheel_coupling_sign)
    : wheel_motor(wheel_motor_),
      leg_motor(leg_motor_),
      leg_offset(leg_offset_),
      bending_direction_(bending_direction),
      wheel_coupling_sign_(wheel_coupling_sign)
{
    // For DM motors, FFW_Current field is repurposed to carry feed-forward TORQUE (Nm)
    // because DM's MIT frame already encodes torque directly (no current→torque conversion).
    mit_set.Position    = 0.0f;
    mit_set.Velocity    = 0.0f;
    mit_set.Pos_KP      = mit_pid_.Pos_KP;
    mit_set.Vel_KD      = mit_pid_.Vel_KD;
    mit_set.FFW_Current = 0.0f;

    default_mit_set = mit_set;

    info.Wheel_RPM = 0.0f;
    info.Leg_POS   = 0.0f;
    info.Leg_Force = 0.0f;
    info.Leg_RPM   = 0.0f;
}

void Wheel_Leg::Init()
{
    if (wheel_motor)
    {
        wheel_motor->enable();
        // HT8115 wheels also need ENTER_MOTOR ritual to accept MIT frames
        for (int i = 0; i < 20; i++)
        {
            wheel_motor->sendCommand(Motors::HT8115::SpecialCommands::ENTER_MOTOR);
            vTaskDelay(pdMS_TO_TICKS(5));
        }
    }

    if (leg_motor)
    {
        // DM motors enter MIT mode directly via enable() (sends 0xFFFFFFFFFFFFFFFC)
        leg_motor->enable();
        vTaskDelay(pdMS_TO_TICKS(20));
    }
    // Initialize Slew Rate Limiter to current position
    if (leg_motor)
    {
        // Wait a bit for feedback to update
        vTaskDelay(pdMS_TO_TICKS(10));
        prev_leg_pos_cmd = Get_LegAngleWrapped();
    }
}

float Wheel_Leg::Wheel_Compensation()
{
    float leg_rpm = 0.0f;
    float leg_pos = 0.0f;

    /**
     * @brief Decoupling Compensation Formula
     *
     *                               r_offset
     * n_Wheel = n_Leg * ( 1.0 +  -------------- * cos(theta_Leg) )
     *                              R_Wheel
     */

    if (leg_motor)
    {
        leg_rpm = leg_motor->getRPMFeedback();
        leg_pos = rad2deg(normalizeAngle(leg_motor->getPositionFeedback() - leg_offset));
    }

    float compensation_rpm = leg_rpm * (1.0f + (ECCENTRIC_OFFSET_r / WHEEL_RADIUS_R) * cosf(deg2rad(leg_pos)));
    return compensation_rpm * wheel_coupling_sign_;
}

float Wheel_Leg::Wheel_Compensation(float leg_omega_radps)
{
    // FF variant: convert commanded leg omega (rad/s) -> rpm and apply the
    // same geometric factor as the FB variant. cos(theta) still uses the
    // actual motor angle so the geometric coupling is instantaneously right,
    // only the velocity term is replaced with the lag-free commanded value.
    float leg_rpm_ff       = leg_omega_radps * (60.0f / (2.0f * 3.14159265f));
    float leg_pos          = Get_LegAngleWrapped();
    float compensation_rpm = leg_rpm_ff * (1.0f + (ECCENTRIC_OFFSET_r / WHEEL_RADIUS_R) * cosf(deg2rad(leg_pos)));
    return compensation_rpm * wheel_coupling_sign_;
}

float Wheel_Leg::VMC_Calculation(float F_z)
{
    float leg_pos   = Get_LegAngleWrapped();  // Degrees
    float theta_rad = deg2rad(leg_pos);

    // Jacobian: Torque = F_z * r * cos(theta)
    // ECCENTRIC_OFFSET_r is in mm, convert to m
    float torque = F_z * (ECCENTRIC_OFFSET_r / 1000.0f) * cosf(theta_rad);

    return torque;
}

float Wheel_Leg::Get_WheelRPM()
{
    if (wheel_motor)
        return wheel_motor->getRPMFeedback();
    return 0.0f;
}

float Wheel_Leg::Get_LegAngleWrapped()
{
    if (leg_motor)
        return rad2deg(normalizeAngle(leg_motor->getPositionFeedback() - leg_offset));
    return 0.0f;
}

float Wheel_Leg::NearestEquivalentTarget(float target_deg) const
{
    // Shift target by whole turns so it lands within +/-180 of the current
    // continuous position -> the leg always takes the short way to an
    // equivalent-height pose, never a multi-turn unwind.
    float diff = target_deg - leg_pos_continuous_;
    while (diff > 180.0f)
        diff -= 360.0f;
    while (diff <= -180.0f)
        diff += 360.0f;
    return leg_pos_continuous_ + diff;
}

float Wheel_Leg::Get_WheelCurrentFeedback()
{
    if (wheel_motor)
        return wheel_motor->getCurrentFeedback();
    return 0.0f;
}

float Wheel_Leg::Get_WheelTemperature()
{
    if (wheel_motor)
        return wheel_motor->getTemperatureFeedback();
    return 0.0f;
}

float Wheel_Leg::Get_WheelOutput()
{
    // HT8115 is MIT-only and does not support getOutput().
    // Use current feedback as a proxy for "output magnitude".
    if (wheel_motor)
        return wheel_motor->getCurrentFeedback();
    return 0.0f;
}

float Wheel_Leg::Get_LegCurrentFeedback()
{
    if (leg_motor)
        return leg_motor->getCurrentFeedback();
    return 0.0f;
}

float Wheel_Leg::Get_LegTorqueFeedback()
{
    if (leg_motor)
        return leg_motor->getTorqueFeedback();
    return 0.0f;
}

float Wheel_Leg::Get_LegGravityTorque()
{
    // Calculate torque needed to hold the leg against gravity
    // Torque = - (m * g * r * cos(theta))
    // Assuming Positive Torque pushes DOWN (extends).
    // Gravity pushes DOWN.
    // So to hold it UP, we need Negative Torque.

    float pos_deg   = Get_LegAngleWrapped();
    float theta_rad = deg2rad(pos_deg);
    float r_meter   = ECCENTRIC_OFFSET_r / 1000.0f;

    // Gravity Torque (Effect of gravity) = m * g * r * cos(theta)
    // This is Positive (pushes down).
    // Compensation Torque (Motor Output) = - Gravity Torque

    return -(LEG_MASS_kg * GRAVITY_g * r_meter * cosf(theta_rad));
}

float Wheel_Leg::Get_LegForce()
{
    if (leg_motor)
        return leg_motor->getTorqueFeedback();
    return 0.0f;
}

float Wheel_Leg::Get_LegVelocity()
{
    if (leg_motor)
        return leg_motor->getRPMFeedback() * 2.0f * M_PI / 60.0f;
    return 0.0f;
}

Wheel_Leg_Params Wheel_Leg::Get_Info()
{
    info.Wheel_RPM = Get_WheelRPM();
    info.Leg_POS   = Get_LegAngleWrapped();
    info.Leg_Force = Get_LegForce();
    info.Leg_RPM   = Get_LegVelocity();
    return info;
}

// === Wheel Pipeline ===

void Wheel_Leg::Set_Wheel_Target(float rpm_cmd)
{
    target_wheel_rpm       = rpm_cmd;
    wheel_compensation_rpm = 0.0f;  // Reset compensation for new cycle
}

void Wheel_Leg::Add_Wheel_Compensation(float comp_rpm) { wheel_compensation_rpm += comp_rpm; }
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

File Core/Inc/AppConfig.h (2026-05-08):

/**
 * @file AppConfig_tempelate.h
 * @author my name (my@domain.com)
 * @brief Configuration file for the whole project
 * @version 0.2
 * @date 2025-4-17
 *
 * @copyright Copyright (c) 2025
 *
 */

/* @how to use this file
 * 1. Copy this file as `AppConfig.h`
 * 2. put it into your template directory
 * 3. modify the content of this file
 * 4. include this file in your project
 */

/* clang-format off */
#if 1 /*Set it to "1" to enable content*/


#ifndef APPCONFIG_H
#define APPCONFIG_H
#endif

#include "Config.h"


//1 for use, 0 for not use
/*==============*
   DEBUG CONFIG
 *==============*/
/*if use debug, some debug watch variables could be seen*/
#define USE_DEBUG 0


/*============*
   IMU CONFIG
 *============*/
/*Config which IMU you use BEGIN*/
#define USE_IMU 1

#if USE_IMU
    #define USE_BMI088 0 // RoboMaster C Board
    #define USE_ICM42688 1 // G/F Board
    /*Config which IMU you use END*/
    #if USE_BMI088
        #define BMI088_SPI hspi1
    #endif // USE_BMI088

    #define IMU_ORIEN_X 0.0f
    #define IMU_ORIEN_Y 0.0f
    #define IMU_ORIEN_Z 0.0f

    #define USE_IMU_HEAT 0

    #if USE_IMU_HEAT
        #define IMU_HEAT_TIM htim20
        #define IMU_HEAT_CHL TIM_CHANNEL_3
        #define IMU_HEAT_TARGET_TEMP 40.0f
        // Config PID params
        #define IMU_HEAT_KP 10.0f
        #define IMU_HEAT_KI 2.0f
        #define IMU_HEAT_KD 5.0f
        #define IMU_HEAT_I_MAX 20.0f // Max integral PWM duty cycle
        #define IMU_HEAT_OUTPUT_MAX 100.0f // Max output PWM duty cycle
    #endif // USE_IMU_HEAT
#endif // USE_IMU

/*Config which Magnetometer you use BEGIN*/
#define USE_MAG 0

#if USE_MAG
    #define USE_LIS3MDL 1  // Select MAG type
#endif // USE_MAG

#if USE_MAG || USE_IMU
    #if defined(STM32F407xx)
        #define SENSOR_SPI hspi1
    #elif defined(STM32G473xx)
        #define SENSOR_SPI hspi1
    #elif defined(STM32G431xx)
        #error "If you are using internal board, MPU6500 driver is not supported here yet XD"
    #else
        #error "Chips are not defined"
    #endif // defined (chips & SENSOR_SPI)
#endif // USE_MAG || USE_IMU


/*================*
   CHASSIS CONFIG
 *================*/
#define USE_CHASSIS_CALCULATOR 0

#if USE_CHASSIS_CALCULATOR
    #define USE_OMNI_CHASSIS 0
    #define USE_MECANUM_CHASSIS 0
    #define USE_SWERVE_CHASSIS 1
#endif // USE_CHASSIS_CALCULATOR


/*=========================*
   POWER CONTROLLER CONFIG
 *=========================*/
#define USE_POWER_CONTROLLER 0

#if USE_POWER_CONTROLLER
/**
 * @note This config indicates whether super cap is connected in your chassis electronic circuit,
 *       but not whether you enable super cap module or not. Make sure you ACTIVATE THE MODULE CORRECTLY,
 *       otherwise power controller would not behave well
 */
#define USE_SUPER_CAPACITOR 0

#if USE_SUPER_CAPACITOR
    #define SUPER_CAPACITOR_CAN_INDEX 0 // 0 for CAN1, 1 for CAN2, 2 for CAN3
    #define SUPER_CAPACITOR_MODEL 2025 // 2024 for RM2024, 2025 for RM2025
    #define CUSTOM_ENERGY_LIMIT 0
    #if CUSTOM_ENERGY_LIMIT
        #define IN_GAME_ENERGY_LIMIT 230
        #define PURE_CAP_ENERGY_LIMIT 50
    #endif // CUSTOM_ENERGY_LIMIT
#endif // USE_SUPER_CAPACITOR
#endif // USE_POWER_CONTROLLER


/*============*
   PID CONFIG
 *============*/
#define PID_TIMEOUT_CUSTOM 0

#if PID_TIMEOUT_CUSTOM
    #define PID_DEFAULT_TIMEOUT pdMS_TO_TICKS(100)
#endif // PID_TIMEOUT_CUSTOM

#define PID_ALPHA_CUSTOM 0

#if PID_ALPHA_CUSTOM
    #define PID_DEFAULT_ALPHA 0.2f
#endif // PID_ALPHA_CUSTOM

#define PID_MAX_OUTPUT_CUSTOM 0

#if PID_MAX_OUTPUT_CUSTOM
    #define PID_DEFAULT_MAX_OUTPUT 10000.0f
#endif // PID_MAX_OUTPUT_CUSTOM


/*==================*
   DJI MOTOR CONFIG
 *==================*/
// NOTE: M3508 is still referenced by Wheel_Leg.hpp / Robot_Config.cpp, which
// are compiled regardless of USE_DM_MOTOR_TEST (Makefile globs Applications/*.cpp).
// DJI motors fully removed from this build. Wheels = HT8115 on CAN2; Legs = DM J10010L_2EC on CAN1.
#define USE_DJI_MOTOR 0

#if USE_DJI_MOTOR
    #define DJI_MOTOR_CONNECTION_TIMEOUT pdMS_TO_TICKS(200)

    #define DJI_MOTOR_USE_CAN1 0
    #define DJI_MOTOR_USE_CAN2 0
    #define DJI_MOTOR_USE_CAN3 0

    #define USE_DJI_GM6020 0
    #define USE_DJI_M2006 0
    #define USE_DJI_M3508 0
#endif // USE_DJI_MOTOR


/*=================*
   DM MOTOR CONFIG
 *=================*/
#define USE_DM_MOTOR 1
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

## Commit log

2026-05-12 fix comfort to ES falling issue
    [Chassis.cpp, Chassis.hpp]
2026-05-29 backup: project state before wired-control feature
    Snapshot of the unified leg-control refactor WIP (Chassis / Climbing_Dynamics /
    Impedance_Controller / Wheel_Leg + UNIFIED_CONTROL_REFACTOR.md design log) before
    starting the wired-control (hall joystick + 3 buttons) feature.
2026-09-15 Refine CLIMBING back-pair sequence
    Final firmware state of the full-size prototype (identical to the binary
    last built on 2026-05-30).
    - Step detection: combined torque-residual + wheel-velocity-drop score with
    separate front/back thresholds, plus a wheel-stall state machine
    - Manual back-pair trigger on a second BTN_X press
    - Inhibit step detection while the chassis is turning
    - Auto chassis advance during CLIMBING; front-leg drop / back-leg extend
    offsets shift the CoM, eased in and out with smoothstep ramps
    - Smoothstep authority ramps for the body-PID dtheta around phase changes
    - UNIFIED_CONTROL_REFACTOR.md: document the consolidated climbing pipeline
    [Chassis.cpp, Chassis.hpp, Climbing_Dynamics.cpp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]
2026-09-15 Move documentation into docs/
    - Report.md -> docs/TECHNICAL_REPORT.md (with a scope note: written for V1)
    - Applications/!Code_Struct.txt -> docs/CODE_STRUCTURE.txt
    - Applications/UNIFIED_CONTROL_REFACTOR.md -> docs/UNIFIED_CONTROL_REFACTOR.md
    - Add README figures (full-size prototype, system architecture, CircLeg geometry, warp modes)
2026-09-15 Add hardware design files
    - hardware/power-distribution-board: KiCad 9 project of the 24 V power distribution board (dual battery input with LM74700 ideal-diode OR-ing, TVS, fuse, XT30 outputs for 8 motors, mini PC, control b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
    - hardware/interface-cad: SolidWorks interface assembly and parts
    [Assem3.SLDASM, Part10.SLDPRT, Part11.SLDPRT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]
2026-09-15 Add README, LICENSE and repository metadata
    - Bilingual README: architecture, control design, build/flash, operator controls, protocol, hardware
    - MIT license for the application code
    - .gitattributes: exclude vendor / generated / hardware files from GitHub language statistics
    - .gitignore: MSYS stackdumps, KiCad local state and backups
2026-09-15 README: add YouTube demo section
    Link the REACHABLE pitch video (https://youtu.be/onJCvx1d8Sw) with a locally stored thumbnail.
2026-09-15 README: project photos and Host V2.0 links
    - Cover photo of the full-size prototype; development and front-view gallery in Hardware; team and ISD group photos (resized, EXIF stripped)
    - Point to Circle_Leg_Host_V2.0 as the current host; note that the vision link (0xFC/0xFD) is not yet consumed by this firmware
2026-09-15 README: thank Jason Chan for the power distribution board
2026-09-16 README: split the Chinese version into README_zh.md
    The in-page language toggle only jumped to a collapsed section. README.md is now English-only and README_zh.md is a full Chinese version with the same layout, images and tables; the toggle at the top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

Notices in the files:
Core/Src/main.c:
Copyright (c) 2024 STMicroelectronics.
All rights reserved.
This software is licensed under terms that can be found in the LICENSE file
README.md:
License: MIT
